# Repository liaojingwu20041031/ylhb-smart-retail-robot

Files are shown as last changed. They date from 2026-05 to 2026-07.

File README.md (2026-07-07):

<div align="center">

# 🤖 YLHB Smart Retail Robot

### ROS 2 + Jetson Orin Nano Super 驱动的多模态智慧零售机器人

**一台会听、会看、会推荐、会导航的比赛级智能零售机器人。**

面向智慧零售竞赛场景，完整打通 **ZLAC8015D 底盘控制 / SLAM 建图 / Nav2 导航 / ZED 2i 视觉 / YOLO 商品识别 / 大模型任务理解 / 连续语音交互 / 现场 UI 总控台**。

<p>
  
  
  
  
  
  
  
  
  
</p>

<p>
  <strong>比赛主线：</strong>
  语音/文字任务理解 -> 货架导航 -> 商品识别 -> 推荐与确认 -> 取货/结算 -> 返回起点
</p>

<p>
  <a href="#-快速开始">快速开始</a> ·
  <a href="#-常用启动命令">启动命令</a> ·
  <a href="#-比赛任务流程">比赛任务</a> ·
  <a href="#-机械与-cad-资料">机械 CAD</a> ·
  <a href="#-系统架构">系统架构</a> ·
  <a href="src/PROJECT_DOC_zh.md">详细文档</a>
</p>

```bash
./scripts/setup_zlac_can.sh can1 500000
./scripts/run_on_jetson.sh competition
```

</div>

---

## 🎯 项目定位

这个仓库是一个面向 Jetson 本机部署的 ROS 2 工作区源码仓库，不是单节点 demo。它把底盘、传感器、导航、视觉检测、大模型任务理解、连续语音和比赛 UI 组织成一套可现场运行的机器人系统。

默认底盘后端是 **ZLAC8015D V4 + SocketCAN/CANopen**；保留 STM32 串口后端作为回退方案。比赛现场推荐从 `./scripts/run_on_jetson.sh competition` 进入，由 UI 和 system supervisor 编排底层、视觉、导航和 AI 节点。

当前版本重点解决的是“能在 Jetson 本机独立跑完整比赛链路”：显示屏 UI 负责现场操作和状态展示，system supervisor 负责按顺序拉起 ROS 2 节点，AI 任务层负责把图片、文字和语音输入转换成机器人可执行事件，底盘/导航/视觉栈负责完成移动和商品识别。

## ✨ 项目亮点

| 方向 | 能力 |
|---|---|
| 🚗 机器人底盘 | ZLAC8015D SocketCAN 默认后端、STM32 串口回退、IMU 驱动、RPLidar 雷达、URDF 模型、EKF 融合 |
| 🗺️ 建图与导航 | SLAM Toolbox 建图、AMCL 定位、Nav2 自主导航、地图保存与加载 |
| 👁️ 视觉感知 | ZED 2i 图像订阅、YOLO26 商品检测、TensorRT 推理、检测结果发布 |
| 🧠 多模态 AI | DashScope/Qwen 图片理解、文字/语音任务解析、商品推荐、结算播报 |
| 🎙️ 连续语音 | eMeet Luna 麦克风输入、唤醒词连续语音会话、ASR 事件路由、TTS 播报 |
| 🖥️ 比赛 UI | A/B/C/D 任务入口、B-1 图片预览、识别结果、购物车、总价、系统总控台 |

> 本仓库不提交 `build/`、`install/`、`log/`、API Key 和模型二进制文件。克隆后需要在目标 Jetson 上本机构建。

## ✅ 当前交付范围

| 模块 | 状态 | 说明 |
|---|---|---|
| Jetson 本机部署 | ✅ 可用 | 依赖安装、构建、运行入口集中在 `scripts/` |
| ZLAC8015D 底盘 | ✅ 默认 | 默认使用 PEAK PCAN-USB 暴露的 SocketCAN `can1`，速率 500000 |
| STM32 底盘 | ✅ 回退 | `base_backend:=stm32` 可切换到旧串口链路 |
| SLAM / Nav2 | ✅ 可用 | 比赛默认地图为 `maps/my_map.yaml`，`src/my_map.yaml` 仅作兼容回退；UI 和移动端保存地图已统一 10 秒等待超时 |
| ZED + YOLO26 | ✅ 可用 | 默认加载 Jetson 本机 TensorRT engine |
| 多模态任务层 | ✅ 可用 | 支持任务书图片、文字指令、商品推荐和购物车状态 |
| 连续语音 / TTS | ✅ 可用 | 默认面向 eMeet Luna，唤醒后进入连续对话 |
| 比赛总控 UI | ✅ 可用 | 提供任务入口、节点控制、地图保存、识别和结算展示 |
| 机械 CAD 资料 | ✅ 已归档 | 小车底盘、万向轮、支架、顶板、Jetson 固定板和语音模块支架等结构件 |
| 演示素材 | ⏳ 补充中 | 后续补充高质量截图、GIF、实机视频和英文 README |

---

## 🧭 系统架构

```mermaid
flowchart TB
    subgraph Interaction[交互与比赛入口]
      User["用户 / 裁判<br/>语音 · 文字 · 任务书图片"]
      UI["比赛显示屏 UI<br/>A/B/C/D 任务入口 · 购物车 · 总控台"]
      Voice["eMeet Luna<br/>唤醒词 · 连续语音 · ASR"]
      TTS["TTS 播报<br/>推荐结果 · 结算状态 · 导航反馈"]
    end

    subgraph Intelligence[AI 任务编排层]
      TaskCore["ylhb_llm 任务核心<br/>意图解析 · 商品推荐 · 任务状态机"]
      Qwen["DashScope / Qwen<br/>视觉理解 · 文本推理 · ASR/TTS"]
      EventBus["/retail_ai/task_event/<br/>任务事件与 UI 状态同步"]
    end

    subgraph ROS[ROS 2 通信与运行时]
      Topics["核心话题<br/>/cmd_vel · /odom · /scan · /image · /detections"]
      Launch["run_on_jetson.sh<br/>bringup · zed · perception · navigation · llm"]
      Supervisor["System Supervisor<br/>比赛节点编排与健康状态"]
    end

    subgraph Robot[机器人执行栈]
      Base["底盘控制<br/>ZLAC8015D 默认 · STM32 回退 · 轮式里程计"]
      IMU["IMU<br/>姿态与角速度"]
      Lidar["RPLidar<br/>2D 激光扫描"]
      ZED["ZED 2i<br/>RGB · Depth · Camera Info"]
      EKF["robot_localization<br/>EKF 位姿融合"]
      SLAM["SLAM Toolbox<br/>建图与地图保存"]
      Nav2["Nav2 / AMCL<br/>定位 · 路径规划 · 避障"]
      Perception["YOLO26 + TensorRT<br/>商品检测 · 调试图像"]
    end

    User --> UI
    User --> Voice
    UI --> TaskCore
    Voice --> TaskCore
    TaskCore <--> Qwen
    TaskCore --> EventBus
    EventBus --> UI
    TaskCore --> TTS

    UI --> Supervisor
    Supervisor --> Launch
    Launch --> Topics
    EventBus --> Nav2

    Topics --> Base
    Base --> Topics
    IMU --> Topics
    Lidar --> Topics
    ZED --> Topics
    Topics --> EKF
    Topics --> SLAM
    Topics --> Nav2
    Topics --> Perception
    Perception --> TaskCore
    Nav2 --> Base
```

---

## 📦 目录结构

```text
.
├── scripts/
│   ├── install_jetson_dependencies.sh   # Jetson 依赖安装
│   ├── build_on_jetson.sh               # 本机构建入口
│   ├── setup_zlac_can.sh                # ZLAC8015D SocketCAN 配置
│   └── run_on_jetson.sh                 # 现场运行入口
├── CAD/
│   └── Retail-Cart-3D-Model/            # 机械同学提供的小车结构 CAD 与 STL 文件
├── maps/
│   ├── my_map.yaml                      # 比赛推荐导航地图
│   └── my_map.pgm
├── src/
│   ├── ylhb_base/                       # 底盘、IMU、URDF、EKF、SLAM、Nav2
│   ├── ylhb_perception/                 # ZED、YOLO/TensorRT、深度定位
│   ├── ylhb_llm/                        # 大模型任务层、语音、TTS、比赛 UI
│   ├── ylhb_interfaces/                 # 自定义 ROS 2 消息
│   ├── rplidar_ros-ros2/                # RPLidar ROS 2 驱动源码
│   ├── zed-ros2-wrapper/                # ZED ROS 2 wrapper 源码
│   ├── PROJECT_DOC_zh.md                # 详细中文开发与比赛调试文档
│   ├── my_map.yaml
│   └── my_map.pgm
├── MIGRATION_JETSON.md                  # Jetson 本机化迁移说明
└── SECURITY.md                          # 安全与密钥规范
```

---

## 🧩 硬件与软件环境

### 硬件组成

| 模块 | 设备 | 用途 |
|---|---|---|
| 主控 | Jetson Orin Nano Super | 运行 ROS 2、Nav2、感知节点、AI 任务层和显示屏 UI |
| 底盘控制 | ZLAC8015D V4 双轮毂伺服驱动器 | 默认后端；通过 SocketCAN/CANopen 接收 `/cmd_vel`，发布 `/odom`、`/zlac8015d/status`、`/zlac8015d/fault` |
| 底盘回退 | STM32 大脑底板 | 串口回退后端；用于旧底盘链路调试和备用运行 |
| 雷达 | RPLidar | 发布 `/scan`，用于 SLAM、AMCL 定位和 Nav2 避障 |
| 相机 | ZED 2i | 发布 RGB 图、深度图和相机内参，供 YOLO 和 3D 粗定位使用 |
| IMU | 底盘 IMU | 与轮式里程计进入 EKF，提高短时位姿稳定性 |
| 语音 | eMeet Luna | 麦克风输入、TTS 播放；推荐录音设备 `plughw:CARD=Luna,DEV=0` |
| 显示 | Jetson 本机 HDMI / 触摸屏 | 比赛 UI、任务 D 驾驶舱和现场总控台 |
| 机械结构 | 自研零售小车底盘与支架 | CAD 文件已归档到 `CAD/Retail-Cart-3D-Model/`，包含底盘、万向轮、顶板、Jetson 固定板和语音模块支架 |

### 软件栈

| 类型 | 组件 |
|---|---|
| 系统 | Ubuntu 22.04 / ROS 2 Humble |
| 导航 | SLAM Toolbox、Nav2、AMCL、robot_localization |
| 视觉 | ZED ROS 2 wrapper、OpenCV、CUDA、TensorRT、YOLO26 |
| AI | DashScope OpenAI 兼容接口、Qwen 视觉/文本/ASR/TTS 模型 |
| UI | PyQt 比赛显示屏总控台 |

---

## 🧱 机械与 CAD 资料

机械结构文件位于 [CAD/Retail-Cart-3D-Model](CAD/Retail-Cart-3D-Model)，用于复现或修改智慧零售小车的物理结构。

| 路径 | 内容 |
|---|---|
| `CAD/Retail-Cart-3D-Model/sldasm/` | SolidWorks 装配文件，包括小车底盘和万向轮装配 |
| `CAD/Retail-Cart-3D-Model/stp/` | SolidWorks 零件文件，包括上底盘、顶板、支撑杆、伸缩柱、电机轮、电池、驱动器、Jetson 固定板、语音模块支架等 |
| `CAD/Retail-Cart-3D-Model/stl/` | 可用于 3D 打印的结构件 STL 文件 |
| `CAD/Retail-Cart-3D-Model/readme.txt` | 3D 打印数量备注 |

当前 3D 打印备注：`支架垫片` 4 个，`固定盖` 2 个，`底盘连接处支架` 2 个。机械件用于承载 Jetson、语音模块、驱动器、电池、底盘连接件和上层展示/交互结构。

---

## 🚀 快速开始

默认工作区路径是 `~/ros2_ws`。如果克隆到其他目录，请先设置：

```bash
export WS_DIR=/path/to/ros2_ws
```

在 Jetson 上克隆仓库：

```bash
cd ~
git clone https://github.com/liaojingwu20041031/ylhb-smart-retail-robot.git ros2_ws
cd ~/ros2_ws
```

安装依赖并构建：

```bash
./scripts/install_jetson_dependencies.sh
./scripts/build_on_jetson.sh
```

`scripts/run_on_jetson.sh` 会自动加载 `/opt/ros/$ROS_DISTRO/setup.bash` 和 `install/setup.bash`，日常启动不需要手动 `source`。

首次连接 ZLAC8015D 前，先配置 CAN 口：

```bash
./scripts/setup_zlac_can.sh can1 500000
ip -br link show can1
```

自研包验证命令：

```bash
PYTHONNOUSERSITE=1 colcon test \
  --packages-select ylhb_base ylhb_perception ylhb_llm ylhb_interfaces \
  --event-handlers console_direct+
```

> 仓库包含 ZED/RPLidar 第三方源码。第三方包用于部署构建，默认不把 vendor lint 作为项目质量门槛；完整 `colcon test` 可能因第三方包格式规则或离线 schema 校验失败。

---

## 🕹️ 常用启动命令

`scripts/run_on_jetson.sh` 是 Jetson 现场推荐入口，支持以下模式：

```text
bringup       启动底盘、IMU、雷达、URDF、EKF
mapping       启动 SLAM Toolbox 建图
navigation    启动 Nav2，默认地图为 ~/ros2_ws/maps/my_map.yaml，缺失时回退到 ~/ros2_ws/src/my_map.yaml
zed           启动 ZED 2i wrapper
perception    启动 TensorRT YOLO 感知节点
llm           启动 AI 任务层、语音节点和可选 UI
competition   启动比赛显示屏 UI、system supervisor 和内嵌 AI 任务层
teleop        启动键盘遥控
```

### 比赛现场一键入口

```bash
./scripts/run_on_jetson.sh competition
```

`competition` 默认启动显示屏 UI、系统 supervisor、AI 任务层、VLM shelf/checkout 节点、连续语音会话和 TTS 播报。进入 UI 的“系统控制”页后，点击“一键启动比赛节点”，supervisor 会按保分模式启动底层栈：

```text
bringup -> zed -> navigation -> llm
```

顺序启动比赛栈。其中 AI 任务层已随 `competition` 内嵌运行，状态会显示为 `embedded`，不会重复启动。

### 当前比赛保分模式

当前 `competition` 入口等价于 score-safe 栈：

- 默认启用 `retail_competition_executor_node`、`vlm_shelf_recognition_node` 和 `vlm_checkout_recognition_node`。
- 机械臂接口预留，默认 `competition_safe_mode:=true enable_real_arm:=false skip_arm_pick_place:=true`，只发布抓取/放置 skipped 成功状态。
- B-1/B-2/C 的商品识别由 ZED 当前图像进入 VLM 完成；YOLO/TensorRT 是增强模式，不是当前保分模式硬依赖。
- 比赛前必须按实际地图标定 S/A/B 点位，更新 `maps/routes/retail_competition_route.json` 或通过 `route_file:=...` 指向实测路线文件。仓库中的占位路线只用于格式示例，不能直接上场。

调试图片兜底：

```bash
./scripts/run_on_jetson.sh competition \
  shelf_image_path:=/home/nvidia/ros2_ws/src/ylhb_llm/test_images/shelf.jpg \
  checkout_image_path:=/home/nvidia/ros2_ws/src/ylhb_llm/test_images/checkout.jpg
```

启用 YOLO/TensorRT 增强感知时，再显式启动：

```bash
./scripts/run_on_jetson.sh competition start_yolo_perception:=true
```

默认参数：

```text
enable_voice:=true
enable_voice_session:=true
enable_capture_voice:=false
enable_tts:=true
audio_input_device:=plughw:CARD=Luna,DEV=0
audio_output_device:=default
tts_voice:=Serena
```

现场临时静音：

```bash
./scripts/run_on_jetson.sh competition enable_tts:=false
```

远程 X11 调试窗口模式：

```bash
./scripts/run_on_jetson.sh competition force_local_display:=false fullscreen:=false
```

### 单模块调试

```bash
# 底盘、IMU、雷达、URDF 和 EKF
./scripts/install_ch341_safe.sh --precheck
./scripts/install_ch341_safe.sh --test-load
sudo ./src/bind_usb.sh
./scripts/setup_zlac_can.sh can1 500000
./scripts/run_on_jetson.sh bringup

# STM32 串口回退底盘
./scripts/run_on_jetson.sh bringup base_backend:=stm32

# ZED 2i
./scripts/run_on_jetson.sh zed

# 大模型任务层，无语音无 TTS
export DASHSCOPE_API_KEY=你的DashScopeKey
./scripts/run_on_jetson.sh llm enable_voice:=false enable_tts:=false
```

启动视觉检测：

```bash
./scripts/run_on_jetson.sh perception \
  model_path:=/home/nvidia/ros2_ws/src/ylhb_perception/models/yolo26.engine \
  backend:=tensorrt \
  imgsz:=960 \
  confidence_threshold:=0.35 \
  max_det:=20 \
  half:=true \
  publish_debug_image:=false \
  log_interval_sec:=2.0 \
  device:=cuda:0
```

---

## 🎙️ 语音交互

项目推荐使用唤醒式连续语音模式。UI 中点击“开启语音模式”后，机器人本地监听人声；听到“小零小零”“小玲小玲”等唤醒词后进入会话。

接入 eMeet Luna 后，先确认系统能看到声卡：

```bash
lsusb | grep -i emeet
arecord -l
aplay -l
```

启动连续语音和 TTS：

```bash
export DASHSCOPE_API_KEY=你的DashScopeKey
./scripts/run_on_jetson.sh llm \
  enable_voice:=true \
  enable_voice_session:=true \
  enable_tts:=true \
  audio_input_device:=plughw:CARD=Luna,DEV=0 \
  audio_output_device:=plughw:CARD=Luna,DEV=0 \
  tts_voice:=Serena
```

连续语音服务和调试话题：

```bash
ros2 service call /retail_ai/start_voice_session std_srvs/srv/Trigger "{}"
ros2 service call /retail_ai/stop_voice_session std_srvs/srv/Trigger "{}"
ros2 topic echo /retail_ai/voice_session_status
ros2 topic echo /retail_ai/voice_command_event
```

---

## 🏁 比赛任务流程

项目按比赛任务 A/B/C/D 组织运行：

| 任务 | 流程 |
|---|---|
| A | 语音、文字或键盘命令转换为 `/cmd_vel`，完成前进、后退、转向、停止等基础动作 |
| B-1 | 导入任务书图片，大模型理解任务，导航到货架 A，识别真实商品，推荐商品，抓取后前往结算区 B |
| B-2 | 接收购物需求或商品指令，大模型像销售员一样给出主推和备选商品；用户确认后才发布取货事件 |
| C | 识别结算区商品，播报商品清单，根据 `products.yaml` 计算总价并返回起点 S |
| D | 通过现场显示屏 UI 展示任务状态、识别结果、播报文本、购物车和结算信息 |

任务书图片分析服务：

```bash
# 图片放在 /home/nvidia/ros2_ws/src/ylhb_llm/test_images
# 目录内只保留一张 .jpg/.jpeg/.png
ros2 service call /retail_ai/start_b1_task std_srvs/srv/Trigger "{}"
```

主要 AI/语音/UI 话题和服务：

```text
/retail_ai/task_event              # TaskEvent，inspect_shelf_for_recommendation / pick_item / checkout / return_start
/retail_ai/task_status             # TaskStatus，执行层回传 started/succeeded/failed/rejected
/retail_ai/sales_dialogue_status   # B-2 销售对话状态 JSON
/retail_ai/voice_command_event     # 连续语音 ASR 事件 JSON
/retail_ai/voice_session_status    # 连续语音会话状态 JSON
/retail_ai/capture_voice           # 单次录音 ASR service，competition 默认关闭
/retail_ai/start_voice_session     # 开启连续语音 service
/retail_ai/stop_voice_session      # 关闭连续语音 service
```

文字入口：

```bash
ros2 topic pub --once /retail_ai/text_command std_msgs/msg/String "{data: '来瓶可乐'}"
ros2 topic pub --once /retail_ai/text_command std_msgs/msg/String "{data: '我口渴了'}"
ros2 topic pub --once /retail_ai/text_command std_msgs/msg/String "{data: '确认'}"
ros2 topic echo /retail_ai/task_event
ros2 topic echo /retail_ai/sales_dialogue_status
ros2 topic echo /retail_ai/say_text
```

---

## 🧰 现场运行自检

比赛前建议按从硬件到任务层的顺序检查，能更快定位是设备、驱动、模型还是 AI Key 问题。

### 设备检查

```bash
# CAN 与 ZLAC8015D
ip -details link show can1

# USB 设备与音频设备
lsusb
arecord -l
aplay -l

# ROS 2 包是否已构建并可见
source install/setup.bash
ros2 pkg list | grep -E 'ylhb_base|ylhb_perception|ylhb_llm|ylhb_interfaces'
```

### 节点与话题检查

```bash
# 底盘与传感器
lsmod | grep -E 'ch341|ch34x'
lsusb
dmesg | grep -i ch34
ls -l /dev/robot_imu /dev/ttyCH341USB* /dev/ttyUSB*
ros2 topic echo /odom
ros2 topic echo /scan
ros2 topic echo /imu/data --once

# ZED 与视觉检测
ros2 topic hz /zed/zed_node/rgb/color/rect/image
ros2 topic echo /detections

# AI 任务层与语音
ros2 topic echo /retail_ai/task_event
ros2 topic echo /retail_ai/task_status
ros2 topic echo /retail_ai/voice_session_status
```

### 常见现场处理

| 现象 | 优先检查 |
|---|---|
| 底盘不响应 `/cmd_vel` | `can1` 是否 `UP`、ZLAC 是否上电、急停/使能状态、`/zlac8015d/fault` |
| 雷达无 `/scan` | `/dev/robot_lidar` 绑定、串口权限、RPLidar 电源和转速 |
| UI 无法显示 | Jetson 本机 `DISPLAY=:0`、HDMI/触摸屏连接、远程调试时加 `force_local_display:=false fullscreen:=false` |
| 视觉节点退出 | `yolo26.engine` 是否存在、engine 是否在当前 Jetson 编译、ZED 图像话题是否有帧 |
| 大模型无响应 | `DASHSCOPE_API_KEY` 是否已导出、网络是否可用、模型参数是否被覆盖 |
| 语音无输入/输出 | eMeet Luna 声卡编号、`audio_input_device` / `audio_output_device`、系统音量和默认声卡 |

---

## 🗺️ 建图与导航

启动建图：

```bash
./scripts/run_on_jetson.sh mapping
```

建图时推荐使用低速键盘遥控：

```bash
source /opt/ros/humble/setup.bash

ros2 run teleop_twist_keyboard teleop_twist_keyboard \
  --ros-args \
  -p speed:=0.08 \
  -p turn:=0.25
```

其中 `speed` 是线速度，单位 `m/s`；`turn` 是角速度，单位 `rad/s`。

启动导航：

```bash
./scripts/run_on_jetson.sh navigation
```

比赛默认把机器人放在建图起点附近，AMCL 启动时会先使用地图原点 `(0, 0, 0)` 发布定位。若现场启动位置偏离建图起点，请先在 RViz/Foxglove 发布 `/initialpose` 覆盖默认位姿，再发送导航目标。

默认导航地图：

```text
~/ros2_ws/maps/my_map.yaml
~/ros2_ws/maps/my_map.pgm
```

推荐比赛导航地图来自实机 SLAM 保存，地图图像为 `195 x 333`，分辨率 `0.05 m/pix`。`~/ros2_ws/src/my_map.yaml` 仅作为兼容回退地图。

巡检路线标注工具的小车俯视模型参考 `/home/nvidia/ros2_DL/src/ylhb_base/config/nav2_params.yaml` 中的 Nav2 `footprint` 和 `footprint_padding`，导出前按整车占地检查地图空闲区。

UI 的“保存地图”默认写入：

```text
~/ros2_ws/src/maps/<map_name>.yaml/.pgm
```

UI 和移动端调试接口保存地图时都会调用：

```bash
ros2 run nav2_map_server map_saver_cli -f <target> --ros-args -p save_map_timeout:=10.0
```

这个等待时间用于覆盖 SLAM Toolbox 发布 `/map` 的实际节奏，避免 Nav2 默认 2 秒订阅等待偶发超时。

导航默认优先读取 `~/ros2_ws/maps/my_map.yaml`。要使用新保存的地图，需要复制成推荐默认地图、保持为回退地图，或启动导航时覆盖 `map:=...`。

---

## 🧠 模型文件说明

模型二进制文件不提交到 GitHub。需要在 Jetson 上准备：

```text
/home/nvidia/ros2_ws/src/ylhb_perception/models/yolo26.onnx
/home/nvidia/ros2_ws/src/ylhb_perception/models/yolo26.engine
```

PC 端导出 ONNX 后，将 `yolo26.onnx` 放入 `src/ylhb_perception/models/`，再在 Jetson 上编译 TensorRT engine：

```bash
ros2 run ylhb_perception export_yolo_trt.py \
  --onnx /home/nvidia/ros2_ws/src/ylhb_perception/models/yolo26.onnx \
  --output /home/nvidia/ros2_ws/src/ylhb_perception/models/yolo26.engine \
  --workspace 2048
```

DashScope API Key 不写入代码。运行图片理解、云端 ASR 或云端 TTS 前，在终端设置：

```bash
export DASHSCOPE_API_KEY=你的DashScopeKey
```

推荐把 API Key 放在本机 shell 配置或现场启动脚本外部注入，不要写进 launch 文件、Python 源码、README 示例之外的配置文件或 Git 跟踪文件。

## 🧪 适合谁参考？

- 正在做 ROS 2 智能车、移动机器人或比赛项目的同学
- 想把 Jetson、ZED、Nav2、YOLO、LLM 接成完整系统的开发者
- 需要智慧零售、服务机器人、多模态交互参考架构的团队
- 想学习“比赛工程如何从 demo 变成交付系统”的机器人爱好者

---

## 📌 Roadmap

- [x] Jetson 本机化部署
- [x] Nav2 / SLAM / EKF 基础运动栈
- [x] ZED 2i + YOLO26 + TensorRT 感知链路
- [x] DashScope/Qwen 多模态任务理解
- [x] 唤醒式连续语音会话
- [x] 比赛显示屏 UI 与 system supervisor
- [ ] 补充高质量演示 GIF、系统截图和视频链接
- [ ] 补充英文 README
- [ ] 增加 CI 检查自研 ROS 2 包
- [ ] 整理可复用的机器人任务编排框架

---

## 🔒 安全与规范

- 不提交 `DASHSCOPE_API_KEY`、`.env`、SSH key、证书或其他本机密钥。
- 不提交 `.onnx`、`.engine`、`.pt` 等模型二进制文件。
- 串口权限优先使用 udev 规则或用户组，不建议长期使用 `chmod 777`。
- 安全和部署注意事项见 [SECURITY.md](SECURITY.md)。

---

## 📚 详细文档

- [src/PROJECT_DOC_zh.md](src/PROJECT_DOC_zh.md)：比赛调试顺序、节点关系、话题流向、启动命令和常见问题。
- [MIGRATION_JETSON.md](MIGRATION_JETSON.md)：从旧 PC 推流识别流程迁移到 Jetson 本机开发、本机构建、本机运行。

---

## ⭐ 支持项目

如果这个项目对你做 ROS 2、Jetson、机器人比赛或多模态 AI Agent 有帮助，欢迎点一个 **Star**。  
后续会继续补充演示视频、部署文档和比赛实战记录。

<div align="center">

**YLHB Smart Retail Robot — 让机器人从“能跑”走向“能听懂、看懂、会执行”。**

</div>

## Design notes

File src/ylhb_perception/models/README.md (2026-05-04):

# YOLO26 模型目录

最终部署流程：

```text
PC 训练 YOLO -> PC 导出 yolo26.onnx -> 复制到 Jetson -> Jetson 编译 yolo26.engine -> Jetson 运行 engine
```

推荐文件：

```text
yolo26.pt       # 原始训练权重，留给 PC 端训练/导出
yolo26.onnx     # PC 端导出的跨平台中间模型
yolo26.engine   # Jetson 本机编译出的 TensorRT FP16 推理引擎，实时检测默认使用
```

Jetson 端一次性编译 TensorRT engine：

```bash
cd ~/ros2_ws
source install/setup.bash
ros2 run ylhb_perception export_yolo_trt.py \
  --onnx /home/nvidia/ros2_ws/src/ylhb_perception/models/yolo26.onnx \
  --output /home/nvidia/ros2_ws/src/ylhb_perception/models/yolo26.engine \
  --workspace 2048
```

Jetson 实时推理：

```bash
ros2 launch ylhb_perception perception.launch.py \
  model_path:=/home/nvidia/ros2_ws/src/ylhb_perception/models/yolo26.engine \
  backend:=tensorrt \
  imgsz:=960 \
  half:=true \
  device:=cuda:0
```

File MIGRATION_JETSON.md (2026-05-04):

# Jetson 本机化迁移备忘

这个文件只记录迁移背景和工程边界。日常使用请看：

```text
~/ros2_ws/src/PROJECT_DOC_zh.md
```

---

## 1. 迁移目标

项目现在以 Jetson Orin Nano Super 本机开发、本机构建、本机运行为准。

默认工作区路径是 `~/ros2_ws`。如需部署到其他目录，先设置：

```bash
export WS_DIR=/path/to/ros2_ws
```

旧流程已经废弃：

```text
PC 端开发
PC 端做视觉识别
开发板向 PC 推流
PC 再把识别结果回传开发板
```

新流程：

```text
Jetson 本机开发
Jetson 本机构建
Jetson 本机启动 ROS 2
Jetson 本机运行 ZED 2i + YOLO26
```

---

## 2. 当前职责边界

```text
ylhb_base
  底盘、IMU、URDF、EKF、雷达、建图、导航

ylhb_perception
  ZED 图像订阅、YOLO26 检测、调试图、ZED 深度定位

zed-ros2-wrapper
  第三方 ZED 驱动，只负责相机输出

rplidar_ros-ros2
  第三方雷达驱动，只负责 /scan 输出
```

---

## 3. 关键变化

新增：

```text
scripts/install_jetson_dependencies.sh
scripts/build_on_jetson.sh
scripts/run_on_jetson.sh
src/ylhb_perception/
```

调整：

```text
src/ylhb_base/scripts/vision_node.py
```

现在它只是兼容桥，不再负责 PC 推流和 PC 回传。

导航默认地图：

```text
~/ros2_ws/src/my_map.yaml
```

---

## 4. 后续开发原则

```text
底盘和导航逻辑继续放 ylhb_base
视觉和 AI 逻辑放 ylhb_perception
不要改第三方 vendor 包来塞业务逻辑
不要再恢复 PC 推流识别流程
```

---

## 5. 最重要的推理入口

PC 端导出 ONNX，Jetson 端执行一次 ONNX 到 TensorRT engine 的本机编译。

PC 端导出 ONNX 后，把文件放到：

```text
/home/nvidia/ros2_ws/src/ylhb_perception/models/yolo26.onnx
```

Jetson 端一次性编译 TensorRT engine：

```bash
ros2 run ylhb_perception export_yolo_trt.py \
  --onnx /home/nvidia/ros2_ws/src/ylhb_perception/models/yolo26.onnx \
  --output /home/nvidia/ros2_ws/src/ylhb_perception/models/yolo26.engine \
  --workspace 2048
```

ZED + YOLO TensorRT 实时检测：

```bash
ros2 launch zed_wrapper zed_camera.launch.py camera_model:=zed2i
ros2 launch ylhb_perception perception.launch.py \
  model_path:=/home/nvidia/ros2_ws/src/ylhb_perception/models/yolo26.engine \
  backend:=tensorrt \
  imgsz:=960 \
  confidence_threshold:=0.35 \
  max_det:=20 \
  half:=true \
  publish_debug_image:=false \
  log_interval_sec:=2.0 \
  device:=cuda:0
```

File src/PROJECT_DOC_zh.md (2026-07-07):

# ROS2 智能车比赛项目开发文档

平台：Jetson Orin Nano Super  
工作区：`~/ros2_ws`  
核心任务：**建图、导航、AI 识别**

本文档按比赛调试顺序编写，重点说明每个模块的技术原理、节点关系、话题流向、启动命令、验收标准和常见问题。

---

## 0. 比赛主流程

比赛准备和调试时，不要从单个脚本开始理解项目，先看主流程：

```text
1. 底层启动
   ZLAC8015D SocketCAN 底盘后端（默认）或 STM32 串口回退 + IMU + 雷达 + URDF + EKF

2. 建图
   RPLidar + 里程计 + TF -> SLAM Toolbox -> 保存 my_map.yaml / my_map.pgm

3. 导航
   已知地图 + AMCL 定位 + Nav2 规划控制 -> /cmd_vel -> 底盘运动

4. AI 识别
   保分模式：ZED 2i 图像 -> VLM shelf/checkout 识别
   增强模式：ZED 2i 图像 -> YOLO26 -> 检测结果 / 本地窗口调试 / 深度定位

5. 比赛整合
   大模型任务层 -> 图片理解 / 语音文字指令解析 / 商品推荐 / 结算流程 -> 导航抓取任务事件
```

当前比赛任务流程按 A/B/C 三类处理：

```text
任务 A-1：
键盘或语音/文字发布前进、后退、左转、右转、停止 -> /cmd_vel -> 底盘动作。
规则没有要求每个基本动作都 AI 播报，所以项目不把“好的，开始前进”写成固定播报。

任务 A-2：
语音交互内容以现场任务书为准，不提前写死台词。语音经 ASR 进入 /retail_ai/text_command。

任务 B-1：
导入任务书图片 -> 大模型理解图片并播报理解内容 -> 发布“去货架 A 识别”事件
-> 到 A 区后识别货架真实商品 -> 从真实货架商品中推荐 1 个最佳商品并播报
-> 抓取推荐商品 -> 导航到结算区 B -> 放置商品。

任务 B-2：
接收文字或语音购物指令 -> 识别目标商品 -> 播报相应信息
-> 导航到货架 A -> 识别货架真实商品 -> 抓取目标商品
-> 导航到结算区 B -> 放置商品 -> 返回起点 S。

任务 C：
接收结算指令 -> 导航到结算区 B -> 识别结算区内所有商品
-> 播报商品清单 -> 返回起点 S -> 按 products.yaml 价格表计算并播报总价。
```

当前比赛保分模式手动启动：

```bash
cd ~/ros2_ws
./scripts/run_on_jetson.sh competition fullscreen:=true
```

该入口默认启用 VLM 货架/结算识别和 safe executor，机械臂真实接口默认跳过。比赛前必须按实际地图标定 S/A/B 点位，更新 `maps/routes/retail_competition_route.json` 或传入 `route_file:=实际路线文件`。仓库里的 A=(1,0)、B=(2,0) 只表示格式占位，不能作为现场路线。

推荐启动顺序：

> **🚗 核心指令：启动底层系统 (Bringup)**

```bash
# 终端 1：启动底盘、IMU、雷达、URDF、EKF
# 进入工作目录并加载环境变量
cd ~/ros2_ws
source /opt/ros/humble/setup.bash
source install/setup.bash
# 一键启动底盘、IMU、雷达、URDF、EKF。IMU 默认必启，缺失会直接报错退出。
ros2 launch ylhb_base bringup.launch.py

# 无 USB-CAN 线或需要回退旧底盘板时：
ros2 launch ylhb_base bringup.launch.py base_backend:=stm32
```

### 底层串口约定与验收

Jetson Orin Nano Super 当前硬件连接约定：

```text
10c4:ea60 Silicon Labs CP210x  -> RPLidar A2M8
1a86:7523 QinHeng CH340        -> IMU 的 USB 转 TTL 模块
0c72:000c PEAK PCAN-USB        -> ZLAC8015D CANopen 底盘
```

比赛机上不要手动 `insmod pcan.ko`、手动运行 `setup_zlac_can.sh`，也不要在每次启动时临时传 `lidar_port:=...`。统一执行一次：

```bash
sudo ./src/bind_usb.sh
```

该脚本会安装并启用 `robot-hardware-guard.service`，循环恢复以下状态：

```text
/dev/robot_lidar -> ttyUSBx       # CP2102 LiDAR，驱动 cp210x
/dev/robot_imu   -> ttyCH341USBx  # CH340 IMU，驱动 usb_ch341
can1             -> PEAK PCAN-USB # 500000 bit/s, berr-reporting on, restart-ms 100, UP
```

安装验收：

```bash
systemctl status robot-hardware-guard.service --no-pager
tail -n 120 /var/log/robot-hardware-guard.log
lsusb -t
ls -l /dev/robot_lidar /dev/robot_imu /dev/ttyUSB* /dev/ttyCH341USB*
ip -details link show can1
```

期望结果：

```text
10c4:ea60 -> Driver=cp210x
1a86:7523 -> Driver=usb_ch341
0c72:000c -> Driver=pcan
/dev/robot_lidar -> ttyUSB0 或其他 ttyUSBx
/dev/robot_imu -> ttyCH341USB0 或其他 ttyCH341USBx
can1 state UP, bitrate 500000, ERROR-ACTIVE
```

`bringup.launch.py` 中 LiDAR 默认使用 `/dev/robot_lidar`。如果 alias 短暂不存在，launch 会按 USB ID `10c4:ea60` 自动查找 CP2102 的 `/dev/ttyUSB*` 作为回退；硬件修复仍然交给 `robot-hardware-guard.service`，ROS launch 只负责检测和报错。

RPLidar A2M8 固定按 `115200` 启动，launch 中将 `lidar_baudrate` 强制作为 int 传给 `rplidar_node`，避免参数类型错误导致节点回退到源码默认的 `1000000` 波特率。正常启动时必须看到类似日志：

```text
RPLidar serial config: port=... baudrate=115200 frame_id=laser_link
RPLidar S/N: ...
RPLidar health status : OK.
current scan mode: Sensitivity ... scan frequency:10.0 Hz
```

雷达验收：

```bash
ros2 topic echo /scan --once
```

如果雷达再次出现 `SL_RESULT_OPERATION_TIMEOUT`，先看日志中的 `RPLidar serial config`，确认端口是 `/dev/robot_lidar` 或 CP2102 回退端口且 `baudrate=115200`；不要再把 CH340 当成雷达端口排查。

IMU 当前注意事项：CH340 能出现在 `lsusb` 里只表示 USB 枚举成功，不等于 Linux 已经创建 tty 串口。当前 Jetson 内核配置为 `# CONFIG_USB_SERIAL_CH341 is not set` 时，`1a86:7523` 不会生成 `/dev/ttyUSB*`。本仓库使用 WCH `usb_ch341` 驱动，正常设备名是 `/dev/ttyCH341USB*`，稳定别名是 `/dev/robot_imu`。标准修复顺序：

```bash
./scripts/install_ch341_safe.sh --precheck
./scripts/install_ch341_safe.sh --test-load
sudo ./src/bind_usb.sh
ls -l /dev/robot_imu /dev/ttyCH341USB* /dev/ttyUSB*
ros2 launch ylhb_base bringup.launch.py
```

当前 IMU 实测为 WIT 协议 `9600` 波特率。`imu_driver` 默认 `baud_rate:=9600`，并保留自动探测常见波特率能力；默认不在每次启动时改写 IMU 模块配置，避免现场设备参数被反复写入。

IMU 验收命令：

```bash
lsmod | grep -E 'ch341|ch34x'
lsusb
dmesg | grep -i ch34
ls -l /dev/robot_imu /dev/ttyCH341USB* /dev/ttyUSB*
ros2 topic echo /imu/data --once
```

> **📷 核心指令：启动 ZED 2i 相机节点**

```bash
# 终端 2：启动 ZED 2i 相机
cd ~/ros2_ws
source install/setup.bash
# 参数详解：
#   camera_model:=zed2i: 显式指定相机型号为 zed2i，底层驱动会自动加载出厂标定的内参与最佳分辨率配置
ros2 launch zed_wrapper zed_camera.launch.py camera_model:=zed2i
```

> **🧠 增强模式：启动 YOLO26 实时感知分析**

```bash
# 终端 3：启动 YOLO26 实时识别
cd ~/ros2_ws
source install/setup.bash
# 运行 AI 视觉流处理。调试看效果时打开本地窗口；比赛时关闭窗口和 ROS2 调试图。
# 参数详析：
#   model_path: Jetson 本机编译出的 TensorRT FP16 engine 绝对路径
#   backend: 日志标识和安全检查用，比赛部署固定使用 tensorrt
#   confidence_threshold: 0.35，偏重识别成功率，后续用连续帧稳定确认过滤误检
#   imgsz: 网络推理重采样尺寸，设定为 960，兼顾远距离小目标识别与算力
#   max_det: 最多保留 20 个检测框，降低 NMS 后处理开销
#   half: 保留 launch 参数兼容；实际精度由 yolo26.engine 编译方式决定
#   publish_debug_image: 默认 false，不走 ROS2 图像调试链路，避免 DDS/Foxglove/rqt 兼容和延迟问题
#   show_debug_window: 调试时设为 true，直接弹出本地 OpenCV 窗口看检测框
#   debug_window_max_hz: 本地调试窗口刷新上限，推荐 10~15
#   log_interval_sec: 每 2 秒输出 FPS、推理耗时和识别摘要
#   device: 保留 launch 参数兼容；C++ TensorRT 节点直接使用 Jetson CUDA Runtime

# 调试模式：直接弹出本地 OpenCV 窗口看检测效果
ros2 launch ylhb_perception perception.launch.py \
  model_path:=/home/nvidia/ros2_ws/src/ylhb_perception/models/yolo26.engine \
  backend:=tensorrt \
  confidence_threshold:=0.35 \
  imgsz:=960 \
  max_det:=20 \
  half:=true \
  publish_debug_image:=false \
  show_debug_window:=true \
  debug_window_max_hz:=15.0 \
  log_interval_sec:=2.0 \
  device:=cuda:0

# 增强模式：关闭所有可视化输出，只发布检测 JSON 和 3D 定位结果
ros2 launch ylhb_perception perception.launch.py \
  model_path:=/home/nvidia/ros2_ws/src/ylhb_perception/models/yolo26.engine \
  backend:=tensorrt \
  confidence_threshold:=0.35 \
  imgsz:=960 \
  max_det:=20 \
  half:=true \
  publish_debug_image:=false \
  show_debug_window:=false \
  debug_window_max_hz:=15.0 \
  log_interval_sec:=2.0 \
  device:=cuda:0
```

```bash
# 终端 4：建图或导航，二选一
# 建图
ros2 launch ylhb_base mapping.launch.py

# 已有地图时导航
ros2 launch ylhb_base navigation.launch.py
```

> **🤖 核心指令：启动大模型任务层**

```bash
# 终端 5：启动任务书图片理解、文字/语音指令解析、商品推荐、结算和播报队列
cd ~/ros2_ws
source /opt/ros/humble/setup.bash
source install/setup.bash

# DashScope API Key 不写进代码，比赛前在终端环境变量里设置
export DASHSCOPE_API_KEY=你的DashScope_API_Key

# 默认语音输入和 TTS 播放关闭，先用文字输入和 say_text 话题调试最稳
ros2 launch ylhb_llm llm.launch.py enable_voice:=false enable_tts:=false
```

任务书图片导入使用 service，不走连续图像 topic：

```bash
ros2 service call /retail_ai/start_b1_task std_srvs/srv/Trigger "{}"
```

B-1 service 不传图片路径；`retail_task_node` 会从
`/home/nvidia/ros2_ws/src/ylhb_llm/test_images` 中读取唯一一张 `.jpg/.jpeg/.png`
任务书图片。

文字指令兜底入口：

```bash
ros2 topic pub --once /retail_ai/text_command std_msgs/msg/String "{data: '来瓶可乐'}"
```

## 显示屏 UI 启动方法

显示屏 UI 是比赛现场总控台，也是任务 D“智慧零售驾驶舱”的展示入口。它负责任务选择、任务启动、建图/导航/感知/AI 任务层控制、识别结果显示、语音播报显示、购物车和总价显示。UI 只做控制入口和状态展示，不参与推荐、结算、抓取的核心决策；UI 进程退出不应影响已经启动的核心 ROS 节点继续运行。

### 单独启动 UI

```bash
cd ~/ros2_ws
ros2 run ylhb_llm retail_display_ui_node
```

单独启动 UI 前需要 ROS 环境已加载；日常比赛不推荐这种方式。若当前终端启用了 `set -u`，手动 `source /opt/ros/humble/setup.bash` 可能报 `AMENT_TRACE_SETUP_FILES: unbound variable`，此时先执行 `set +u` 再 source，或直接使用下面的 `run_on_jetson.sh` 包装脚本。

### 通过 launch 启动 UI

```bash
cd ~/ros2_ws
ros2 launch ylhb_llm llm.launch.py enable_display_ui:=true
```

通过 `ros2 launch` 手动启动同样要求 ROS 环境已加载。若只是比赛现场使用，优先使用 `./scripts/run_on_jetson.sh competition`。

### 比赛现场推荐启动

```bash
cd ~/ros2_ws
./scripts/run_on_jetson.sh competition
```

`run_on_jetson.sh` 会自动加载 `/opt/ros/$ROS_DISTRO/setup.bash` 和 `~/ros2_ws/install/setup.bash`，并且在加载时临时关闭 `set -u`，避免 ROS 官方 setup 脚本读取未定义变量时报错。

`competition` 默认启用连续语音会话和 TTS 播报；按键式单次录音 service 默认关闭。实际 launch 参数为 `enable_voice:=true`、`enable_voice_session:=true`、`enable_capture_voice:=false`、`enable_tts:=true`、`audio_input_device:=plughw:CARD=Luna,DEV=0`、`audio_output_device:=default`。启动后进入 UI 的“系统控制”页，点击“一键启动比赛节点”，由总控台启动底盘/雷达、ZED、感知和导航；不需要再手动打开其它终端。若现场需要临时静音：

```bash
./scripts/run_on_jetson.sh competition enable_tts:=false
```

`run_on_jetson.sh` 支持的模式：

```text
bringup       启动底盘、IMU、雷达、URDF、EKF
mapping       启动 slam_toolbox 建图
navigation    启动 Nav2，默认优先读取 ~/ros2_ws/maps/my_map.yaml，缺失时回退到 ~/ros2_ws/src/my_map.yaml
zed           启动 ZED 2i wrapper
perception    启动 TensorRT YOLO 感知节点
llm           启动 AI 任务层、语音和 UI 相关节点
competition   启动比赛 UI、supervisor 和内嵌 AI 任务层
teleop        启动键盘遥控
```

比赛现场接 Jetson 物理显示屏时使用本机显示：

```bash
export DISPLAY=:0
```

`DISPLAY=localhost:10.0` 是 SSH X11 转发，会把窗口转发到发起 SSH 的电脑；比赛现场物理屏幕必须使用 `DISPLAY=:0`。`competition` 脚本会自动把 SSH 转发 DISPLAY 改成 `:0`。如需远程 X11 调试，可使用：

```bash
./scripts/run_on_jetson.sh competition force_local_display:=false fullscreen:=false
```

`competition` 脚本会在启动 UI 前执行 X11 显示电源设置，关闭屏保、空白屏和 DPMS 省电息屏，等价于：

```bash
DISPLAY=:0 xset s off
DISPLAY=:0 xset s noblank
DISPLAY=:0 xset -dpms
```

如果现场仍然息屏，先确认当前 X11 状态：

```bash
DISPLAY=:0 xset q
```

其中 `timeout` 应为 `0`，`DPMS is Disabled` 表示已关闭自动息屏。

`competition` 脚本还会默认启动 IBus 拼音输入法。物理屏幕上的系统虚拟键盘仍按屏幕手势调出，项目不再额外启动 Onboard。等价环境变量如下：

```bash
GTK_IM_MODULE=ibus
QT_IM_MODULE=ibus
XMODIFIERS=@im=ibus
ibus-daemon -drx
ibus engine pinyin
```

如果现场不需要中文输入法：

```bash
ENABLE_CHINESE_IME=false ./scripts/run_on_jetson.sh competition
```

如果需要排查输入法：

```bash
ps aux | grep ibus-daemon
ibus engine
ibus list-engine | grep -i pinyin
```

常用参数：

| 参数 | 作用 | 默认值 |
|---|---|---|
| `enable_task_layer` | 是否启动 AI 任务层节点 | `true` |
| `enable_display_ui` | 是否启动显示屏 UI | `true` |
| `enable_system_supervisor` | 是否启动系统控制 supervisor | `true` |
| `task_image_dir` | B-1 任务书图片目录 | `/home/nvidia/ros2_ws/src/ylhb_llm/test_images` |
| `fullscreen` | 是否全屏显示 | `true` |
| `display` | UI 显示目标 | `:0` |
| `force_local_display` | 是否强制使用 `display` 覆盖 SSH DISPLAY | `true` |
| `initial_system_mode` | 初始系统状态 | `ready` |
| `enable_voice` | 是否启用 eMeet Luna 语音输入 | `true` |
| `enable_voice_session` | 是否启用唤醒式连续语音会话 | `true` |
| `enable_capture_voice` | 是否启用按键式单次录音 service | `false` |
| `enable_tts` | 是否启用 eMeet Luna TTS 播报 | `true` |
| `audio_input_device` | 录音设备 | `plughw:CARD=Luna,DEV=0` |
| `audio_output_device` | 播放设备 | `default` |

B-1 图片导入规则：

```text
图片放入 task_image_dir。
支持 .jpg、.jpeg、.png。
目录内没有图片时，UI 显示“未找到任务书图片”。
目录内有多张图片时，UI 显示“目录内存在多张图片，请只保留一张”。
目录内只有一张图片时，UI 显示预览并允许启动 B-1。
```

如果 B-1 显示 `/retail_ai/start_b1_task` 服务未就绪，说明 `retail_task_node` 没有启动或还没完成启动。UI 会先尝试通过 supervisor 启动 AI 任务层并等待服务；仍失败时，检查：

```bash
ros2 service list | grep /retail_ai/start_b1_task
ros2 node list | grep retail_task_node
```

UI 顶部状态栏会显示 `B1服务: 就绪/未就绪`。刚启动比赛总控时，`retail_task_node` 需要几秒钟完成初始化；此时不要立即连续点击 B-1。推荐使用 `./scripts/run_on_jetson.sh competition`，不要只单独运行 `ros2 run ylhb_llm retail_display_ui_node` 后直接点 B-1。

全屏说明：UI 默认使用无边框全屏并设置到主屏幕可用尺寸，目标是占据 Jetson 物理显示器整个屏幕且避开系统面板保留区域。如需窗口化调试：

```bash
./scripts/run_on_jetson.sh competition fullscreen:=false
```

小屏适配说明：UI 会读取主屏幕可用尺寸；当屏幕宽度小于 `1180` 或高度小于 `760` 时，自动启用紧凑布局。紧凑布局会把顶部状态栏拆成多行、缩小按钮/表头/标签间距，并把主内容放入可滚动区域，因此在低分辨率显示屏上即使内容高度超过屏幕，也不会出现窗口内容被全屏边界裁掉后无法访问的问题。

如果显示器或 HDMI 采集器本身开启了过扫描，可能仍会裁掉最外侧几个像素。此时优先在显示器菜单中关闭 overscan/过扫描，或先窗口化验证：

```bash
./scripts/run_on_jetson.sh competition fullscreen:=false
```

### TTS 音频链路调试

需要单独验证播报链路时，直接向统一播报话题
`/retail_ai/say_text` 发布消息。这两条命令只依赖 `voice_output_node` 和 TTS，
不依赖 `retail_task_node`、任务 C 状态机、导航、视觉识别或 service，不能作为正式任务 C 流程。

默认展示商品固定为：

```text
一袋薯片
一瓶营养快线
```

根据 `/home/nvidia/ros2_ws/src/ylhb_llm/config/products.yaml`，当前价格为薯片
3 元、营养快线 6 元，共 2 件商品、总额 9 元。

第一个后台终端指令模拟“完成结算区内的商品信息识别”：

```bash
ros2 topic pub --once /retail_ai/say_text ylhb_interfaces/msg/SayText \
  "{task_id: 'manual_checkout_inspect', priority: 9, interrupt: true, text: '完成结算区内的商品信息识别，结算区域内有一袋薯片和一瓶营养快线。'}"
```

预期播报：

```text
完成结算区内的商品信息识别，结算区域内有一袋薯片和一瓶营养快线。
```

第二个后台终端指令模拟“机器人回到起点区域”：

```bash
ros2 topic pub --once /retail_ai/say_text ylhb_interfaces/msg/SayText \
  "{task_id: 'manual_checkout_total', priority: 9, interrupt: true, text: '已回到起点区域，您购买的2件商品总额为9元。'}"
```

预期播报：

```text
已回到起点区域，您购买的2件商品总额为9元。
```

两个指令彼此独立，可以在同一个后台终端依次执行，也可以分别放在两个终端中。
`interrupt: true` 会终止当前播报并清空等待队列，确保比赛现场立即播放这段语音。
若命令发布成功但没有声音，检查：

```bash
ros2 node list | grep voice_output_node
ros2 topic info /retail_ai/say_text -v
ros2 param get /voice_output_node enabled
ros2 param get /voice_output_node tts_enabled
```

### 系统控制页

UI 的“系统控制”页通过 `/retail_ai/system_command` 向 `system_supervisor_node` 发送 JSON 命令，supervisor 负责启动/停止外部 launch 进程，并通过 `/retail_ai/system_status` 回传状态。

系统控制页提供：

```text
一键启动/停止比赛节点
启动/停止底盘和雷达 bringup
启动/停止手动建图
保存地图
启动/停止导航
启动/停止 ZED
启动/重启感知节点
启动/停止 AI 任务层
软件急停
返回准备状态
```

“一键启动比赛节点”在保分模式下按 `bringup -> zed -> navigation -> llm` 顺序启动比赛栈，不强制启动 YOLO/TensorRT 感知。需要增强模式时使用 `start_yolo_perception:=true` 或手动 `start_perception`。`competition` 启动时 AI 任务层已经内嵌运行，因此 supervisor 会把 `llm` 状态显示为 `embedded`，不会重复启动同名 AI 节点。“一键停止比赛节点”会停止导航、感知、ZED 和底盘/雷达，保留 UI、AI 任务层和语音节点继续运行。

supervisor 支持的命令：

```text
start_bringup / stop_bringup
start_mapping / stop_mapping
start_navigation / stop_navigation / restart_navigation
start_zed / stop_zed
start_perception / stop_perception / restart_perception
start_llm / stop_llm
save_map
emergency_stop
start_competition_stack
stop_competition_stack
return_ready
```

`/retail_ai/system_status` 是 JSON 字符串，核心字段：

```text
bringup/mapping/navigation/zed/perception/llm  # running/stopped/embedded
last_command                                   # 最近处理的命令
success                                        # 最近命令是否成功
message                                        # 最近命令说明或错误原因
timestamp                                      # 状态发布时间戳
```

`save_map` 默认保存到 `~/ros2_ws/src/maps/<map_name>.yaml/.pgm`；直接启动 `navigation.launch.py` 默认优先读取 `~/ros2_ws/maps/my_map.yaml`，缺失时回退到 `~/ros2_ws/src/my_map.yaml`。supervisor 的 `start_navigation` 默认同样使用 `~/ros2_ws/maps/my_map.yaml`；如果要让新地图成为默认导航地图，需要复制到推荐比赛地图路径，或启动导航时覆盖 `map:=...`。

常用系统命令：

```bash
ros2 topic pub --once /retail_ai/system_command std_msgs/msg/String \
  "{data: '{\"command\":\"start_mapping\"}'}"

ros2 topic pub --once /retail_ai/system_command std_msgs/msg/String \
  "{data: '{\"command\":\"save_map\",\"map_name\":\"retail_map_2026\"}'}"

ros2 topic echo /retail_ai/system_status
```

系统模式：

```text
sleep     休眠
ready     比赛准备
mapping   手动建图中
running   任务执行中
fault     异常待处理
```

`mapping` 模式下允许 A-1/手动控制和保存地图，禁止启动 B/C/D 任务。软件急停会发布 `system_mode=fault`、发布“停止”、并向 `/cmd_vel` 连续发布全零 Twist；这不是安全级物理急停，真正急停仍应依赖硬件急停按钮。

### 比赛现场推荐操作顺序

1. 启动 Jetson。
2. 打开显示屏 UI：`./scripts/run_on_jetson.sh competition`。
3. 点击“进入准备”。
4. 如需重新建图，进入“系统控制”页，点击“启动建图”。
5. 手动遥控机器人完成建图。
6. 点击“保存地图”，输入地图名称。
7. 点击“停止建图”。
8. 点击“启动导航”。
9. 点击“启动 ZED”和“启动感知”。
10. 点击“启动 AI 任务层”。
11. 进入任务页面，依次执行 A、B、C、D。
12. 出现异常时点击“软件急停”。
13. 任务完成后点击“任务完成，返回准备”。

---

## 1. 系统架构图

```mermaid
flowchart TB
  classDef hardware fill:#f5f5f5,stroke:#9e9e9e,stroke-width:2px,color:#000
  classDef vendor fill:#fff3e0,stroke:#ffb74d,stroke-width:2px,color:#000
  classDef base fill:#e1f5fe,stroke:#4fc3f7,stroke-width:2px,color:#000
  classDef ai fill:#f3e5f5,stroke:#ce93d8,stroke-width:2px,color:#000

  subgraph HW["硬件物理层"]
    ZLACDRV["ZLAC8015D V4<br/>双轮毂伺服驱动器"]:::hardware
    STM32["STM32 大脑底板<br/>串口底盘回退"]:::hardware
    IMUHW["IMU 陀螺仪<br/>提供姿态感知"]:::hardware
    LIDARHW["RPLidar 激光雷达<br/>构建2D环境轮廓"]:::hardware
    ZEDHW["ZED 2i 双目相机<br/>采集彩图和深度"]:::hardware
  end

  subgraph VENDOR["传感器驱动层"]
    RPLIDAR["rplidar_node<br/>雷达串口数据转 LaserScan"]:::vendor
    ZED["zed_wrapper<br/>发布彩色图和深度图"]:::vendor
  end

  subgraph BASE["导航控制层 ylhb_base"]
    ZLACCTL["zlac8015d_canopen_controller<br/>默认执行 /cmd_vel 并发布 /odom"]:::base
    BASECTL["base_controller<br/>STM32 回退后端"]:::base
    IMUNODE["imu_driver<br/>发布 /imu/data"]:::base
    RSP["robot_state_publisher<br/>发布机器人 TF"]:::base
    EKF["ekf_filter_node<br/>融合底盘和 IMU"]:::base
    SLAM["slam_toolbox<br/>构建2D地图"]:::base
    NAV2["Nav2<br/>定位、规划、避障、控制"]:::base
  end

  subgraph AI["视觉感知层 ylhb_perception"]
    YOLO["yolo_detector_node<br/>TensorRT 加载 yolo26.engine"]:::ai
    LOCALIZER["object_localizer_node.py<br/>检测框加深度估算3D位置"]:::ai
    LEGACY["vision_node.py<br/>旧接口兼容桥"]:::ai
  end

  subgraph LLM["大模型任务层 ylhb_llm + ylhb_interfaces"]
    RETAIL["retail_task_node<br/>图片理解、指令解析、推荐、购物车、结算"]:::ai
    VIN["voice_input_node<br/>eMeet Luna 按钮录音 + ASR"]:::ai
    VOUT["voice_output_node<br/>播报队列 + TTS播放"]:::ai
  end

  ZLACDRV <== "SocketCAN / CANopen" ==> ZLACCTL
  STM32 <== "串口通信" ==> BASECTL
  IMUHW -- "I2C/TTL" --> IMUNODE
  LIDARHW -- "串口数据" --> RPLIDAR
  ZEDHW -- "USB 3.0" --> ZED

  ZLACCTL -- "/odom" --> EKF
  BASECTL -. "base_backend:=stm32 时 /odom" .-> EKF
  IMUNODE -- "/imu/data" --> EKF
  EKF -- "TF: odom -> base_footprint" --> NAV2
  RSP -- "/tf_static" --> NAV2
  
  RPLIDAR -- "/scan" --> SLAM
  RPLIDAR -- "/scan" --> NAV2
  SLAM -- "/map" --> NAV2
  NAV2 -- "/cmd_vel" --> ZLACCTL
  NAV2 -. "base_backend:=stm32" .-> BASECTL

  ZED -- "/zed/.../image" --> YOLO
  YOLO -- "/perception/detections" --> LOCALIZER
  YOLO -- "本地 OpenCV 窗口" --> VIEW(("屏幕查看检测框"))
  YOLO -. "/perception/debug_image 可选" .-> VIEW
  
  ZED -- "/zed/.../depth_registered" --> LOCALIZER
  ZED -- "/zed/.../camera_info" --> LOCALIZER
  
  LOCALIZER -- "/perception/target_pose" --> TASK(("比赛上层逻辑脚本"))
  LOCALIZER -- "/perception/localized_objects" --> RETAIL
  RETAIL -- "/retail_ai/task_event" --> TASK
  TASK -- "/retail_ai/task_status" --> RETAIL
  RETAIL -- "/retail_ai/say_text" --> VOUT
  VIN -- "/retail_ai/text_command" --> RETAIL
  
  YOLO -. "兼容转发" .-> LEGACY
  LOCALIZER -. "兼容转发" .-> LEGACY
```

---

## 2. 工程目录

```text
~/ros2_ws/
├── scripts/
│   ├── install_jetson_dependencies.sh   # 安装 Jetson 依赖
│   ├── build_on_jetson.sh               # 一键编译
│   ├── diagnose_pcan.sh                 # 只读诊断 PEAK PCAN-USB 和内核 CAN 状态
│   ├── install_peak_pcan_safe.sh        # 安全编译/临时加载 PEAK PCAN-USB SocketCAN 驱动
│   ├── install_ch341_safe.sh            # 安全检查/编译/临时加载 CH340/CH341 IMU 串口驱动
│   ├── setup_zlac_can.sh                # 配置 can1/PEAK PCAN-USB SocketCAN 给 ZLAC8015D
│   └── run_on_jetson.sh                 # 常用启动包装
├── docs/
│   └── pcan_peak_setup.md               # PEAK PCAN-USB 安全排查和安装记录
├── src/
│   ├── ylhb_base/                       # 底盘、IMU、雷达编排、建图、导航
│   ├── ylhb_perception/                 # ZED + YOLO26 + 深度定位
│   ├── ylhb_interfaces/                 # 大模型任务层自定义 msg/srv 接口
│   ├── ylhb_llm/                        # 图片理解、语音/文字指令、推荐、结算、播报
│   ├── zed-ros2-wrapper/                # ZED 第三方驱动
│   ├── rplidar_ros-ros2/                # RPLidar 第三方驱动
│   ├── bind_usb.sh                      # 固定 IMU / 雷达串口名
│   ├── my_map.yaml                      # 导航回退地图
│   └── my_map.pgm                       # 导航回退地图图像
├── maps/
│   ├── my_map.yaml                      # navigation.launch.py 优先读取的默认导航地图
│   └── my_map.pgm                       # navigation.launch.py 优先读取的默认导航地图图像
├── build/
├── install/
└── log/
```

`ylhb_base` 主要文件：

```text
src/ylhb_base/
├── launch/bringup.launch.py             # 底层一键启动
├── launch/mapping.launch.py             # 建图启动
├── launch/navigation.launch.py          # 导航启动
├── config/ekf.yaml                      # EKF 参数
├── config/base_kinematics.yaml          # 底盘运动学、限速、轮向、frame 参数
├── config/zlac8015d.yaml                # ZLAC8015D CANopen 通信和看门狗参数
├── config/slam_toolbox_params.yaml      # 建图参数
├── config/nav2_params.yaml              # Nav2 参数
├── src/zlac8015d_canopen_controller.cpp # 默认 ZLAC SocketCAN 底盘后端
├── src/base_controller.cpp              # STM32 串口底盘回退后端
├── src/imu_driver.cpp                   # IMU 节点
└── urdf/ylhb.urdf.xacro                 # 机器人模型与传感器安装位姿
```

`ylhb_perception` 主要文件：

```text
src/ylhb_perception/
├── config/detector.yaml                 # 视觉参数
├── launch/perception.launch.py          # YOLO + 深度定位启动
├── models/yolo26.pt                     # YOLO26 原始训练权重，留给 PC 端训练/导出
├── models/yolo26.onnx                   # PC 端导出的跨平台中间模型
├── models/yolo26.engine                 # Jetson 本机编译出的 TensorRT FP16 推理引擎
├── src/yolo_detector_node.cpp           # C++ TensorRT 实时检测节点，比赛默认入口
├── scripts/export_yolo_trt.py           # Jetson 端 ONNX -> TensorRT engine 编译工具
├── scripts/yolo_detector_node.py        # Python 版检测节点，保留作调试/回退
└── scripts/object_localizer_node.py     # 检测框 + 深度粗定位
```

`ylhb_interfaces` 主要文件：

```text
src/ylhb_interfaces/
├── msg/TaskEvent.msg                    # AI 层发给导航/抓取层的结构化任务事件
├── msg/TaskStatus.msg                   # 导航/抓取层回传执行状态
├── msg/SayText.msg                      # 带 task_id、优先级、打断标记的播报请求
├── msg/VoiceStatus.msg                  # 当前是否正在播报
├── msg/CartState.msg                    # 当前购物车状态和总价
└── msg/RecognizedProduct.msg            # 商品 ID、名称、数量、单价、来源等
```

`ylhb_llm` 主要文件：

```text
src/ylhb_llm/
├── config/products.yaml                 # 16类比赛商品：标准ID、中文名、别名、价格、推荐权重
├── config/llm.yaml                      # 大模型、话题、超时、语音开关等默认参数
├── launch/llm.launch.py                 # 大模型任务层一键启动
└── ylhb_llm/
    ├── retail_task_node.py              # 图片理解、文字/语音指令、推荐、购物车、结算
    ├── basic_motion_command_node.py     # A-1 基本运动文字/语音指令转 /cmd_vel
    ├── qwen_client.py                   # DashScope OpenAI兼容接口封装
    ├── product_catalog.py               # 商品库读取、别名匹配、推荐评分
    ├── voice_input_node.py              # eMeet Luna/ALSA按键录音、ASR、发布文字指令
    └── voice_output_node.py             # 播报队列、TTS、本机播放、语音状态
```

---

## 3. 节点与话题总表

### 3.1 底层与定位

| 节点 | 包 | 订阅 | 发布 | 技术作用 |
|---|---|---|---|---|
| `zlac8015d_canopen_controller` | `ylhb_base` | `/cmd_vel` | `/odom`, `/zlac8015d/status`, `/zlac8015d/fault` | 默认底盘后端；通过 SocketCAN + CANopen 直接控制 ZLAC8015D 双轮毂伺服 |
| `base_controller` | `ylhb_base` | `/cmd_vel` | `/odom` | STM32 串口底盘回退后端，使用 `base_backend:=stm32` 启动 |
| `imu_driver` | `ylhb_base` | 无 | `/imu/data` | 读取 IMU，加速度、角速度、姿态进入 ROS |
| `rplidar_node` | `rplidar_ros` | 无 | `/scan` | 发布 2D 激光雷达扫描 |
| `robot_state_publisher` | `robot_state_publisher` | URDF 参数 | `/tf_static`, `/tf` | 根据 URDF 发布传感器相对车体的坐标关系 |
| `ekf_filter_node` | `robot_localization` | `/odom`, `/imu/data` | `/odometry/filtered`, `/tf` | 融合轮式里程计和 IMU，使 `odom -> base_footprint` 更稳定 |

### 3.2 建图与导航

| 节点 | 包 | 订阅 | 发布 | 技术作用 |
|---|---|---|---|---|
| `slam_toolbox` | `slam_toolbox` | `/scan`, `/tf` | `/map`, `/tf` | 用激光雷达和位姿估计构建 2D 占据栅格地图 |
| `map_server` | `nav2_map_server` | 地图 yaml 参数 | `/map` | 加载已有地图 |
| `amcl` | `nav2_amcl` | `/scan`, `/map`, `/tf` | `/amcl_pose`, `/particle_cloud`, `/tf` | 在已知地图中估计机器人位置 |
| `planner_server` | `nav2_planner` | `/goal_pose`, `/map`, `/tf` | `/plan` | 生成全局路径 |
| `controller_server` | `nav2_controller` | `/plan`, `/tf`, 代价地图 | `/cmd_vel` | 根据路径和障碍物输出速度指令 |

### 3.3 ZED 与 AI 识别

| 节点 | 包 | 订阅 | 发布 | 技术作用 |
|---|---|---|---|---|
| `zed_wrapper` | `zed-ros2-wrapper` | ZED 2i 硬件 | `/zed/zed_node/rgb/color/rect/image`, `/zed/zed_node/depth/depth_registered`, `/zed/zed_node/rgb/color/rect/camera_info` | 发布 RGB 图、深度图、相机内参 |
| `yolo_detector_node` | `ylhb_perception` | `/zed/zed_node/rgb/color/rect/image` | `/perception/detections`, 可选 `/perception/debug_image`，可选本地调试窗口 | C++ TensorRT 直接加载 `yolo26.engine` 做 YOLO26 检测 |
| `object_localizer_node.py` | `ylhb_perception` | `/perception/detections`, 深度图, camera_info | `/perception/localized_objects`, `/perception/target_pose` | 由 2D 检测框和深度图估算目标 3D 坐标 |
| `vision_node.py` | `ylhb_base` | `/perception/detections`, `/perception/target_pose` | `/vision/result`, `/vision/target_pose` | 兼容旧接口 |

### 3.4 大模型任务层

| 节点 | 包 | 订阅/服务输入 | 发布/服务输出 | 技术作用 |
|---|---|---|---|---|
| `retail_task_node` | `ylhb_llm` | `/retail_ai/text_command`, `/retail_ai/system_mode`, `/perception/localized_objects`, `/retail_ai/task_status`, service `/retail_ai/start_b1_task` | `/retail_ai/task_event`, `/retail_ai/say_text`, `/retail_ai/cart` | 比赛任务大脑：任务书图片理解、指令解析、商品推荐、购物车和结算 |
| `basic_motion_command_node` | `ylhb_llm` | `/retail_ai/text_command`, `/retail_ai/system_mode` | `/cmd_vel` | A-1 基本运动控制：前进、后退、左转、右转、停止；不强制播报 |
| `voice_input_node` | `ylhb_llm` | service `/retail_ai/capture_voice`, eMeet Luna/ALSA 录音 | `/retail_ai/text_command` | 按键式单次录音 ASR；默认关闭，UI 可按需调用 |
| `voice_session_node` | `ylhb_llm` | service `/retail_ai/start_voice_session`, `/retail_ai/stop_voice_session`, `/retail_ai/voice_status` | `/retail_ai/voice_command_event`, `/retail_ai/voice_session_status`, `/retail_ai/say_text` | 唤醒式连续语音会话，VAD 分段、ASR、发布语音命令事件 |
| `voice_command_router_node` | `ylhb_llm` | `/retail_ai/voice_command_event`, `/retail_ai/sales_dialogue_status`, `/retail_ai/system_mode`, `/retail_ai/task_status` | `/retail_ai/text_command`, `/retail_ai/say_text` | 把连续语音事件路由到安全指令、A-1、B-2、C 等入口 |
| `voice_output_node` | `ylhb_llm` | `/retail_ai/say_text` | `/retail_ai/voice_status` | 播报队列，支持优先级和打断；可只打印文本，也可启用 TTS 播放 |
| `retail_display_ui_node` | `ylhb_llm` | 任务按钮、系统状态、识别结果、购物车、语音状态 | `/retail_ai/system_mode`, `/retail_ai/system_command`, `/retail_ai/text_command`, `/cmd_vel`, service `/retail_ai/start_b1_task`, `/retail_ai/start_voice_session`, `/retail_ai/stop_voice_session`, `/retail_ai/capture_voice` | 比赛现场显示屏、状态控制台和任务 D 驾驶舱 |
| `system_supervisor_node` | `ylhb_llm` | `/retail_ai/system_command` | `/retail_ai/system_status`, `/retail_ai/system_mode`, `/cmd_vel` | 启动/停止建图、导航、感知、AI任务层，保存地图，集中管理外部进程 |

### 3.5 大模型接口说明

任务 B-1 启动服务：

```text
/retail_ai/start_b1_task
```

类型：`std_srvs/srv/Trigger`

请求：

```text
空。retail_task_node 从 task_image_dir 中读取唯一一张 jpg/jpeg/png 图片。
```

响应：

```text
bool success          # 是否启动成功
string message        # JSON 字符串，包含 task_id、stage、image_path、say_text、error
```

注意：该 service 只触发 B-1 任务入口，不表示 B-1 完成。调用成功后，`retail_task_node` 会先播报图片理解内容，并发布去货架 A 识别的 `/retail_ai/task_event`；到货架并完成识别后，才从真实货架商品中推荐最终商品。

系统模式控制：

```text
/retail_ai/system_mode
```

类型：`std_msgs/msg/String`，取值 `sleep/ready/mapping/running/fault`。发布端和订阅端都使用 `RELIABLE + TRANSIENT_LOCAL + KEEP_LAST + depth=1`，UI 启动后立即发布 `initial_system_mode`。`sleep/mapping/fault` 下任务层忽略普通任务输入，基础运动节点在 `mapping` 下允许手动建图运动，在 `sleep/fault` 下只响应停止。

软件急停/停止运动由 UI 同时执行：

```text
1. 发布 /retail_ai/system_mode = fault
2. 发布 /retail_ai/text_command = "停止"
3. 向 /cmd_vel 连续发布 5 次全零 Twist
```

这不是安全级物理急停；导航取消和机械臂 stop/hold 由后续执行层对接。

文字或语音转写后的指令入口：

```text
/retail_ai/text_command
```

类型：`std_msgs/msg/String`

示例：

```bash
ros2 topic pub --once /retail_ai/text_command std_msgs/msg/String "{data: '来瓶可乐'}"
ros2 topic pub --once /retail_ai/text_command std_msgs/msg/String "{data: '一共多少钱'}"
```

结构化任务事件：

```text
/retail_ai/task_event
```

类型：`ylhb_interfaces/msg/TaskEvent`

核心字段：

```text
task_id        # 幂等任务ID，导航/抓取层回传状态时必须带回
intent         # pick_item / checkout / unknown
item_id        # 商品标准ID，例如 water_nongfu
item_name      # 商品中文名，例如 农夫山泉矿泉水
destination    # checkout / shelf / start 等目标阶段
confidence     # AI/规则综合置信度
source         # image / voice / text / checkout
requires_ack   # 是否需要执行层回传 /retail_ai/task_status
raw_json       # 调试用原始 JSON，不作为跨节点核心字段
```

常见事件流：

```text
B-1：inspect_shelf_for_recommendation -> 执行层回传 inspect_shelf succeeded -> pick_item
B-2：pick_item；语音来源默认需要先确认推荐，再发布取货事件
C：checkout -> 执行层回传 checkout_inspect succeeded -> return_start -> 执行层回传 return_start succeeded
```

执行状态回传：

```text
/retail_ai/task_status
```

类型：`ylhb_interfaces/msg/TaskStatus`

导航/抓取层执行后发布：

```text
task_id     # 必须和 task_event 中一致
stage       # navigate_to_shelf / grasp / navigate_to_checkout / place / return_start
status      # started / succeeded / failed / rejected
reason      # 失败或拒绝原因
```

如果 `retail_task_node` 收到 `succeeded`，才把对应商品加入购物车；收到 `failed/rejected`，只播报失败原因，不更新购物车。

播报请求：

```text
/retail_ai/say_text
```

类型：`ylhb_interfaces/msg/SayText`

核心字段：

```text
task_id      # 播报关联任务
priority     # 数字越大越优先播放
interrupt    # true 时清空等待队列
text         # 要播报的中文文本
```

语音状态：

```text
/retail_ai/voice_status
```

类型：`ylhb_interfaces/msg/VoiceStatus`

内容：

```text
speaking           # 当前是否正在播报
current_task_id    # 正在播报的任务ID
```

购物车状态：

```text
/retail_ai/cart
```

类型：`ylhb_interfaces/msg/CartState`

`CartState` 中的商品使用 `RecognizedProduct`，包含标准商品 ID、名称、类别、数量、单价、置信度、来源任务 ID、来源、检测框和调试 JSON。总价由本地代码按 `products.yaml` 计算，不让大模型直接决定最终金额。

销售对话状态：

```text
/retail_ai/sales_dialogue_status
```

类型：`std_msgs/msg/String`，内容为 JSON。`retail_task_node` 发布，UI 和 `voice_command_router_node` 订阅。用于 B-2 销售对话，包含 `active/state/primary_product_name/related_products/pending_product_name/waiting_for/last_reply` 等字段。连续语音模式下，明确商品或需求型购物都会先进入待确认状态；用户确认后才发布 `pick_item` 取货事件。

连续语音事件：

```text
/retail_ai/voice_command_event
```

类型：`std_msgs/msg/String`，内容为 JSON。`voice_session_node` 发布，字段包括 `source/session_id/utterance_id/text/raw_asr_text/awakened/contains_wake_phrase/confidence/timestamp`。`voice_command_router_node` 会转发为 `/retail_ai/text_command` JSON，并附加 `route` 字段。

连续语音状态：

```text
/retail_ai/voice_session_status
```

类型：`std_msgs/msg/String`，内容为 JSON。核心字段包括 `enabled/state/wake_phrase/awakened/session_id/waiting_for/is_tts_playing/is_recording/asr_fail_count/last_asr_text/last_published_text/last_error/last_update_time`。

语音 service：

```text
/retail_ai/capture_voice          # std_srvs/srv/Trigger，按键式单次录音 ASR
/retail_ai/start_voice_session    # std_srvs/srv/Trigger，开启唤醒式连续语音
/retail_ai/stop_voice_session     # std_srvs/srv/Trigger，关闭唤醒式连续语音
```

### 3.6 发布/订阅内容细化说明

这一节解释上面表格中每个核心话题“里面是什么、谁用它、比赛调试时怎么看”。

#### 3.6.1 底盘后端：`zlac8015d_canopen_controller` / `base_controller`

默认底盘后端是 `zlac8015d_canopen_controller`，Jetson 通过 PEAK PCAN-USB 暴露出的 SocketCAN `can1` 直接和 ZLAC8015D V4 CANopen 驱动器通信。旧 `base_controller` 保留为 STM32 串口回退方案：

```bash
# 默认 ZLAC SocketCAN 后端
ros2 launch ylhb_base bringup.launch.py base_backend:=zlac

# STM32 串口回退
ros2 launch ylhb_base bringup.launch.py base_backend:=stm32 base_port:=/dev/ttyS1
```

ZLAC 参数文件：

```text
config/base_kinematics.yaml  # 轮半径、轮距、最大线/角速度、左右轮方向、frame
config/zlac8015d.yaml        # CAN 接口、node_id、SDO 超时、看门狗、反馈/故障检查频率
```

当前现场默认 CAN 接口：

```text
can0  # Jetson 板载 mttcan，不接 ZLAC8015D 底盘链路
can1  # PEAK PCAN-USB，已验证为 ZLAC8015D 底盘链路
```

PCAN-USB 验证结论：

```text
lsusb 能看到 0c72:000c PEAK System PCAN-USB
pcan 模块为 PEAK Linux driver 8.15.2，netdev/SocketCAN 模式
ip -details link show can1 显示 can1 UP、ERROR-ACTIVE、bitrate 500000
candump -tz can1 能收到 ZLAC8015D 上电心跳：701#00
```

底盘上线前必须先保证 `can1` 是 500k 并处于 UP：

```bash
cd ~/ros2_ws
./scripts/setup_zlac_can.sh can1 500000
ip -details link show can1
candump -tz can1
```

`candump` 看到 `701#00` 后，再启动默认 ZLAC 后端。否则先排查 PEAK 驱动、USB-CAN 线、CANH/CANL、终端电阻、ZLAC 上电和波特率。

订阅：

```text
/cmd_vel                   # 接收外部线速度、角速度控制底层电机的订阅话题
```

消息类型：`geometry_msgs/msg/Twist`

内容含义：

```text
linear.x    # 前进/后退线速度，单位 m/s
angular.z   # 原地左转/右转角速度，单位 rad/s
```

谁会发布：

```text
Nav2 controller_server       # 自动导航时发布
teleop_twist_keyboard        # 手动键盘遥控时发布
上层比赛任务逻辑             # 需要直接控制底盘时发布
```

发布：

```text
/odom                      # 由底盘编码器积分推算出的基础轮式里程计发布话题
/zlac8015d/status          # ZLAC 后端状态、心跳、实际左右轮 rpm；默认约 1Hz
/zlac8015d/fault           # ZLAC 非零故障码；不会循环自动清故障
```

消息类型：`nav_msgs/msg/Odometry`

内容含义：

```text
header.frame_id = odom
child_frame_id  = base_footprint
pose            # 底盘根据轮速积分得到的位置和姿态
twist           # 当前线速度和角速度
```

谁会订阅：

```text
ekf_filter_node      # 和 IMU 融合，得到更稳定的里程计
Nav2 / SLAM          # 间接使用 odom 相关 TF 和位姿估计
调试工具             # 用于观察底盘反馈是否正常
```

检查命令：

```bash
ros2 topic echo /cmd_vel --once
ros2 topic echo /odom --once
ros2 topic echo /zlac8015d/status
ros2 topic echo /zlac8015d/fault
```

比赛调试重点：

```text
如果 /cmd_vel 有数据但 /odom 不变，默认优先查 CAN 接口、ZLAC 使能、故障码和电机反馈。
使用 base_backend:=stm32 时，再查底盘串口、STM32、电机反馈。
如果 /odom 跳变，导航和建图都会受影响。
```

#### 3.6.2 `imu_driver`

`imu_driver` 把 IMU 串口数据转换成 ROS 标准 IMU 消息。

当前现场 IMU 是 WIT 协议串口模块，实测输出为 `9600` 波特率，原始帧包含：

```text
0x55 0x51  # 加速度
0x55 0x52  # 角速度
0x55 0x53  # 姿态角
```

默认启动参数：

```text
serial_port:=/dev/robot_imu
baud_rate:=9600
auto_detect_baud:=true
configure_on_start:=false
```

`auto_detect_baud` 会在需要时尝试 `115200/9600/57600/38400/19200`，确认能解析 WIT 帧后再进入正常读取。`configure_on_start` 默认关闭，不在每次 ROS 启动时向 IMU 写入解锁、改波特率、保存等配置命令；只有明确需要重新配置 IMU 模块时才手动打开。

发布：

```text
/imu/data                  # 以极高频率发布角速度、加速度、姿态四元数的 IMU 话题
```

消息类型：`sensor_msgs/msg/Imu`

内容含义：

```text
orientation          # 姿态四元数
angular_velocity     # 角速度，主要关注 z 轴 yaw 角速度
linear_acceleration  # 线加速度
covariance           # 传感器噪声估计，EKF 会使用
```

谁会订阅：

```text
ekf_filter_node      # 与 /odom 融合
调试工具             # 检查 IMU 是否稳定、有无漂移
```

检查命令：

```bash
ros2 topic echo /imu/data --once
ros2 topic hz /imu/data
ros2 topic info /imu/data --no-daemon
```

比赛调试重点：

```text
IMU yaw 方向如果反了，机器人转向估计会错。
IMU 数据剧烈跳动，EKF 输出也会不稳定。
如果 Foxglove 能看到 /imu/data，但 ros2 topic echo 偶发抓不到，先用 --no-daemon 查真实 ROS 图，避免 daemon 缓存误判。
如果 /dev/robot_imu 存在但没有 /imu/data，先检查 imu_driver 是否启动，再确认波特率是否为 9600。
```

#### 3.6.3 `rplidar_node`

`rplidar_node` 把 RPLidar 激光扫描转换成 ROS 标准雷达消息。

发布：

```text
/scan                      # 发布激光雷达 360° 环境切面距离测算数据的的话题
```

消息类型：`sensor_msgs/msg/LaserScan`

内容含义：

```text
angle_min / angle_max        # 扫描角度范围
angle_increment              # 每个点之间的角度间隔
range_min / range_max        # 有效测距范围
ranges                       # 每个角度方向上的距离数组
intensities                  # 反射强度，可选
header.frame_id = laser_link # 雷达坐标系
```

谁会订阅：

```text
slam_toolbox     # 建图
amcl             # 已知地图下定位
Nav2 costmap     # 障碍物避障
```

检查命令：

```bash
ros2 topic echo /scan --once
ros2 topic hz /scan
```

比赛调试重点：

```text
/scan 没有数据，建图和导航都无法工作。
laser_link 的 TF 如果安装角度不对，地图会歪，导航也会偏。
```

#### 3.6.4 `robot_state_publisher`

`robot_state_publisher` 不直接读取硬件，它读取 URDF，把机器人结构发布到 TF。

输入：

```text
robot_description 参数
```

来源：

```text
~/ros2_ws/src/ylhb_base/urdf/ylhb.urdf.xacro
```

发布：

```text
/tf_static                 # 广播机器人自身零部件不变的固定物理距离安装点 (如 base_link 到 radar_link)
/tf                        # 广播机器人移动时随时在变的外部坐标系参照系变换
```

内容含义：

```text
base_footprint -> laser_link               # 雷达安装位置
base_footprint -> imu_link                 # IMU 安装位置
base_footprint -> zed_left_camera_frame... # 相机安装位置，后续可继续完善
```

谁会使用：

```text
slam_toolbox       # 需要知道雷达相对车体的位置
Nav2               # 需要完整 TF 树
object_localizer   # 后续如果要把相机坐标目标转换到车体/地图坐标，需要 TF
```

检查命令：

```bash
ros2 run tf2_tools view_frames
```

比赛调试重点：

```text
TF 树断了，建图/导航/定位都会出问题。
雷达或相机的实际安装位置变了，必须同步改 URDF。
```

#### 3.6.5 `ekf_filter_node`

`ekf_filter_node` 负责融合轮式里程计和 IMU。

订阅：

```text
/odom
/imu/data
```

发布：

```text
/odometry/filtered         # 经卡尔曼滤波消除误差后提供更平滑平稳表现的增强里程计
/tf                        # 发布包含增强状态计算得出的 Odom 等相关坐标转换
```

发布内容含义：

```text
/odometry/filtered
  融合后的里程计，通常比纯轮速 /odom 更稳定。

/tf
  主要发布 odom -> base_footprint 的动态坐标变换。
```

谁会使用：

```text
slam_toolbox
Nav2
AMCL
TF 查询工具
```

检查命令：

```bash
ros2 topic echo /odometry/filtered --once
ros2 run tf2_ros tf2_echo odom base_footprint
```

比赛调试重点：

```text
EKF 输出不稳，建图会弯，导航会飘。
如果 /odom 和 /imu/data 时间戳异常，EKF 可能融合失败。
```

#### 3.6.6 `slam_toolbox`

`slam_toolbox` 是建图核心。

订阅：

```text
/scan
/tf
```

发布：

```text
/map                       # SLAM 算法拼图输出的代表场地的全局 2D 占据栅格地图
/tf                        # SLAM 定位闭环后发布的 /map 坐标对 /odom 的补偿链接
```

发布内容含义：

```text
/map
  nav_msgs/msg/OccupancyGrid
  2D 占据栅格地图。
  白色通常表示可通行，黑色表示障碍，灰色表示未知区域。

/tf
  map -> odom
  表示地图坐标系和里程计坐标系之间的修正关系。
```

谁会使用：

```text
RViz / Foxglove       # 可视化地图
map_saver_cli         # 保存地图
Nav2                  # 如果边建图边导航，会使用地图和 TF
```

检查命令：

```bash
ros2 topic echo /map --once
ros2 run tf2_ros tf2_echo map odom
```

比赛调试重点：

```text
/map 质量决定后续导航质量。
建图时车速要慢，转弯要稳，避免地图重影和弯曲。
```

#### 3.6.7 Nav2：`map_server` / `amcl` / `planner_server` / `controller_server`

Nav2 是导航核心，不是单个节点，而是一组节点协同工作。

`map_server` 发布：

```text
/map
```

内容：

```text
从 my_map.yaml 和 my_map.pgm 读取出来的静态地图。
```

`amcl` 订阅：

```text
/scan
/map
/tf
```

`amcl` 发布：

```text
/amcl_pose                 # 粒子滤波算法判断后认定的场内大概率坐标和朝向
/particle_cloud            # 可视化表现粒子群在寻找定位过程中的收敛置信云团
/tf                        # 纠正并发送 map 与 odom 间的实时误差对齐参数
```

内容：

```text
/amcl_pose
  机器人在 map 坐标系下的估计位置。

/particle_cloud
  AMCL 粒子云，用于观察定位是否收敛。

/tf
  map -> odom，用于把里程计坐标修正到地图坐标。
```

`planner_server` 发布：

```text
/plan                      # 导航服务根据障碍物计算出的一条从起点到终点的全局通行轨迹
```

内容：

```text
从当前位置到目标点的全局路径。
```

`controller_server` 发布：

```text
/cmd_vel                   # 接收外部线速度、角速度控制底层电机的订阅话题
```

内容：

```text
最终给底盘执行的速度指令。
```

检查命令：

```bash
ros2 topic echo /amcl_pose --once
ros2 topic echo /plan --once
ros2 topic echo /cmd_vel
```

比赛调试重点：

```text
有 /plan 但没有 /cmd_vel：多半是局部控制器、代价地图或 lifecycle 状态问题。
有 /cmd_vel 但车不动：多半是底盘串口或 base_controller 问题。
```

#### 3.6.8 `zed_wrapper`

`zed_wrapper` 是 ZED 2i 的 ROS2 驱动。

发布：

```text
/zed/zed_node/rgb/color/rect/image         # ZED 2i 左目主镜头截取且畸变纠正的彩色图像流
/zed/zed_node/rgb/color/rect/camera_info   # 附带出厂级内参矩阵的相机信息
/zed/zed_node/depth/depth_registered       # 与彩色图像完全对齐的高精度深度距离图
/zed/zed_node/point_cloud/cloud_registered # 相机解算出的三维空间点云数据
/zed/zed_node/imu/data                     # 相机内部自带的高频高精 IMU 传感器数据
/zed/zed_node/pose                         # 相机自带空间测算视觉里程计输出的位姿
```

核心内容：

```text
/zed/zed_node/rgb/color/rect/image
  sensor_msgs/msg/Image
  YOLO26 的实时输入图像。
  当前实测分辨率为 960x540，encoding 可能是 bgra8。

/zed/zed_node/rgb/color/rect/camera_info
  sensor_msgs/msg/CameraInfo
  RGB 相机内参，包含 fx/fy/cx/cy。

/zed/zed_node/depth/depth_registered
  sensor_msgs/msg/Image
  与 RGB 对齐的深度图。
```

谁会订阅：

```text
yolo_detector_node          # 订阅 RGB 图像，C++ TensorRT 实时检测
object_localizer_node.py    # 订阅深度图和相机内参
```

检查命令：

```bash
ros2 topic hz /zed/zed_node/rgb/color/rect/image
ros2 topic echo /zed/zed_node/rgb/color/rect/camera_info --once
ros2 topic hz /zed/zed_node/depth/depth_registered
ros2 run rqt_image_view rqt_image_view /zed/zed_node/rgb/color/rect/image
```

注意：

```text
ros2 topic echo 图像时看到 data=Uint8Array(...) 是正常现象。
RGB 图像内容可用 rqt_image_view 或 Foxglove 看；YOLO 检测效果优先用本地 OpenCV 调试窗口看。
不要在 Foxglove/rqt 中订阅深度图的 `/compressed` 话题，32FC1 深度图不支持 JPEG compressed。
```

#### 3.6.9 `yolo_detector_node`

`yolo_detector_node` 是实时 2D 目标检测节点。比赛默认入口是 C++ 可执行文件，不再通过 Python/Ultralytics 跑实时图像流。

订阅：

```text
/zed/zed_node/rgb/color/rect/image
```

输入内容：

```text
ZED 2i RGB 图像。
节点内部通过 cv_bridge 转成 OpenCV 图像，OpenCV 做 letterbox 预处理，再用 TensorRT Runtime 直接加载 yolo26.engine 推理。
```

发布：

```text
/perception/detections     # 高级视觉 AI 检测完毕后用 JSON 打包的所有场上目标信标
/perception/debug_image    # 可选 ROS2 调试图。默认不依赖它看效果，避免 DDS/Foxglove/rqt 影响时效
本地 OpenCV 窗口       # 推荐调试方式。show_debug_window:=true 时直接弹窗显示检测框
```

`/perception/detections` 内容：

```text
std_msgs/msg/String
内容是 JSON 字符串。
```

JSON 字段：

```text
header.stamp       # 图像时间戳
header.frame_id    # 图像坐标系，当前通常是 zed_left_camera_frame_optical
backend            # 配置中的后端标识，比赛部署为 tensorrt
actual_backend     # 节点根据模型后缀识别出的实际后端，.engine 对应 tensorrt
model_path         # 当前模型路径
detections         # 检测框数组
```

每个 detection：

```text
class_id       # 模型输出的类别编号
class_name     # 根据 detector.yaml 的 class_names 翻译；未配置时为 class_id 字符串
confidence     # 置信度
bbox_xyxy      # 检测框左上角/右下角像素坐标
bbox_center    # 检测框中心点像素坐标
bbox_size      # 检测框宽高
```

`/perception/debug_image` 内容：

```text
sensor_msgs/msg/Image
可选 ROS2 带框调试图。默认关闭；本机调试优先用 OpenCV 窗口。
```

检查命令：

```bash
ros2 topic echo /perception/detections --once
```

调试看效果优先使用：

```bash
ros2 launch ylhb_perception perception.launch.py \
  model_path:=/home/nvidia/ros2_ws/src/ylhb_perception/models/yolo26.engine \
  publish_debug_image:=false \
  show_debug_window:=true \
  debug_window_max_hz:=15.0
```

只有需要远程录制或给 Foxglove 转发时，才打开 `/perception/debug_image`。

比赛调试重点：

```text
ROS 不决定识别类别，类别由 YOLO 模型 names 决定。
如果一直识别成 refrigerator、tv、sheep，说明模型类别表是 COCO 80 类，不是比赛目标模型。
C++ 节点不会自动读取 .pt 的 names；需要可读类别名时，在 detector.yaml 的 class_names 里按 class_id 顺序填写。
```

#### 3.6.10 `object_localizer_node.py`

`object_localizer_node.py` 把 2D 检测框粗略转换成 3D 目标点。

订阅：

```text
/perception/detections
/zed/zed_node/depth/depth_registered
/zed/zed_node/rgb/color/rect/camera_info
```

处理逻辑：

```text
1. 读取 YOLO 检测框。
2. 取检测框中心点像素坐标。
3. 在 ZED 深度图中读取中心点附近深度。
4. 使用 camera_info 中的 fx/fy/cx/cy 反投影到相机坐标系。
5. 发布目标 3D 粗定位结果。
```

发布：

```text
/perception/localized_objects  # 把 2D 上的物品切入深度图求算出 3D 绝对物理空间相对位姿的目标集合
/perception/target_pose        # 单独取出的场内首个有效被跟踪猎物的专属空间指向三维坐标系
```

`/perception/localized_objects` 内容：

```text
std_msgs/msg/String
JSON 字符串，包含每个目标的类别、置信度、2D 框和相机坐标系下的 x/y/z。
```

`/perception/target_pose` 内容：

```text
geometry_msgs/msg/PoseStamped
默认发布第一个有效目标的位置。
frame_id 当前为 zed_left_camera_frame_optical。
```

检查命令：

```bash
ros2 topic echo /perception/localized_objects --once
ros2 topic echo /perception/target_pose --once
```

比赛调试重点：

```text
当前 3D 定位是基础版本，只取检测框中心附近深度。
如果目标边缘深度不准，3D 点会跳。
后续可改成检测框区域内深度中位数、类别筛选、目标跟踪。
```

#### 3.6.11 `vision_node.py`

`vision_node.py` 是旧接口兼容桥，不是主视觉节点。

订阅：

```text
/perception/detections
/perception/target_pose
```

发布：

```text
/vision/result             # 这是为过去老旧的系统模块留下来的兼容器：发布图像物体分类数据
/vision/target_pose        # 这是为过去代码保留的兼容器：给出目标相较于车身的方向与距离等三维信息
```

作用：

```text
如果旧比赛任务代码还订阅 /vision/result 或 /vision/target_pose，
可以临时启动这个桥接节点，不需要改旧代码。
新代码建议直接订阅 /perception/*。
```

启动：

```bash
ros2 run ylhb_base vision_node.py
```

---

## 4. 建图流程

建图是比赛前最重要的基础工作。地图质量会直接影响导航稳定性。

### 4.1 技术原理

本项目使用 `slam_toolbox` 做 2D 激光建图。

建图依赖三类信息：

```text
1. /scan
   RPLidar 发布的激光雷达扫描，用于观察墙、障碍物和场地边界。

2. odom -> base_footprint
   EKF 融合后的机器人短时间运动估计，用于告诉 SLAM 机器人大概怎么移动。

3. base_footprint -> laser_link
   URDF 发布的雷达安装位姿，用于把雷达数据转换到机器人坐标系。
```

建图数据流：

```mermaid
flowchart LR
  RPLidar[/scan/] --> SLAM[slam_toolbox]
  ODOM[odom->base_footprint TF] --> SLAM
  URDF[base_footprint->laser_link TF] --> SLAM
  SLAM --> MAP[/map/]
  SLAM --> TF[map->odom TF]
  MAP --> SAVE[map_saver_cli 保存 my_map]
```

### 4.2 启动建图

终端 1，启动底层：

```bash
cd ~/ros2_ws
source install/setup.bash
ros2 launch ylhb_base bringup.launch.py
```

终端 2，启动建图：

> **🗺️ 核心指令：执行环境建图操作**

```bash
cd ~/ros2_ws
source install/setup.bash
# 启动 SLAM 节点 (默认使用 slam_toolbox)。
# 它会根据小车底盘移动的里程计 (odom) 与 激光雷达数据 (scan) 绘制地图
ros2 launch ylhb_base mapping.launch.py
```

终端 3，键盘遥控：

```bash
source /opt/ros/humble/setup.bash

ros2 run teleop_twist_keyboard teleop_twist_keyboard \
  --ros-args \
  -p speed:=0.15 \
  -p turn:=0.25
```

其中 `speed` 是线速度，单位 `m/s`；`turn` 是角速度，单位 `rad/s`。

### 4.3 建图时怎么开车

建图时不要乱跑，建议按比赛场地边界缓慢走一圈：

```text
1. 先沿场地外圈慢速移动。
2. 再补充中间区域。
3. 转弯要慢，避免里程计和雷达匹配跳变。
4. 不要频繁高速原地旋转。
5. 每走一段观察 /map 是否变形。
```

### 4.4 保存地图

> **💾 核心指令：持久化保存场地地图**

```bash
# 进入你期望存储地图的数据目录
cd ~/ros2_ws/src
source ~/ros2_ws/install/setup.bash

# 调用 Nav2 提供的终端保存工具
# 参数讲解：
#   -f my_map: 代表你要保存的文件基础名（File）。系统会自动生成对应的 my_map.yaml (元数据表) 和 my_map.pgm (二维栅格画布)
#   save_map_timeout:=10.0: 等待 /map 的最长时间，避免默认 2 秒在当前 SLAM 发布节奏下偶发超时
ros2 run nav2_map_server map_saver_cli -f my_map --ros-args -p save_map_timeout:=10.0
```

输出：

```text
~/ros2_ws/src/my_map.yaml
~/ros2_ws/src/my_map.pgm
```

UI 的“保存地图”按钮走 `system_supervisor_node` 的 `save_map` 命令，默认保存到：

```text
~/ros2_ws/src/maps/<map_name>.yaml
~/ros2_ws/src/maps/<map_name>.pgm
```

移动端 `/api/debug/mapping/save` 也走同一类 `map_saver_cli` 保存逻辑。两个入口都已统一设置 `save_map_timeout:=10.0`，失败时会保留 `map_saver_cli` 的输出，便于区分 `/map` 超时、路径权限、目录不存在等问题。

当前仓库回退地图 `~/ros2_ws/src/my_map.yaml/.pgm` 已更新为实机保存结果，地图尺寸 `195 x 333`，分辨率 `0.05 m/pix`。直接启动 `navigation.launch.py` 时会优先使用 `~/ros2_ws/maps/my_map.yaml`，该文件不存在才回退到 `~/ros2_ws/src/my_map.yaml`。

注意：保存目录和导航默认地图是两个概念。比赛推荐导航地图是 `~/ros2_ws/maps/my_map.yaml`，`~/ros2_ws/src/my_map.yaml` 只作为兼容回退。如果要使用 UI 保存的新地图，需要复制成推荐默认地图，或启动导航时显式传 `map:=~/ros2_ws/src/maps/<map_name>.yaml`。

### 4.5 建图验收标准

地图可用于比赛前，至少满足：

```text
1. 墙体边界不明显弯曲。
2. 闭环后地图没有大幅错位。
3. 小车回到起点时，地图位置能对上。
4. 雷达障碍物在 RViz/Foxglove 中和实际障碍位置基本一致。
5. 保存后的 my_map.yaml 能被 navigation.launch.py 正常加载。
```

### 4.6 建图常见问题

地图弯曲：

```text
常见原因：车速太快、轮式里程计不准、雷达安装 TF 不准。
处理：降低速度，检查 ylhb.urdf.xacro 中 laser_link 位姿。
```

地图重影：

```text
常见原因：回环匹配失败或机器人转弯太快。
处理：沿边界慢速走，避免快速原地旋转。
```

没有 `/map`：

```bash
ros2 topic list | grep map
ros2 topic echo /scan --once
ros2 run tf2_tools view_frames
```

---

## 5. 导航流程

导航是比赛执行阶段的核心。它依赖一张稳定地图和正确的 TF 树。

### 5.1 技术原理

Nav2 导航链路：

```text
地图加载：
  map_server 读取 my_map.yaml，发布 /map

定位：
  AMCL 使用 /scan 和 /map 估计机器人在地图中的位置

规划：
  planner_server 根据目标点生成全局路径 /plan

控制：
  controller_server 根据路径、局部代价地图和当前位姿发布 /cmd_vel

执行：
  base_controller 接收 /cmd_vel，通过串口控制 STM32 底盘
```

导航数据流：

```mermaid
flowchart LR
  MAP[my_map.yaml] --> MAPSERVER[map_server]
  MAPSERVER --> MAPTOPIC[/map/]
  SCAN[/scan/] --> AMCL[amcl]
  MAPTOPIC --> AMCL
  TF[/tf/] --> AMCL
  AMCL --> MAPODOM[map->odom TF]
  GOAL[/goal_pose/] --> PLANNER[planner_server]
  MAPTOPIC --> PLANNER
  PLANNER --> PLAN[/plan/]
  PLAN --> CONTROLLER[controller_server]
  CONTROLLER --> CMD[/cmd_vel/]
  CMD --> BASE[base_controller]
```

### 5.2 启动导航

终端 1，启动底层：

```bash
cd ~/ros2_ws
source install/setup.bash
ros2 launch ylhb_base bringup.launch.py
```

终端 2，启动导航：

> **🧭 核心指令：启动 Nav2 路径规划和定位**

```bash
cd ~/ros2_ws
source install/setup.bash
# 启动 Nav2 的导航栈，这会自动启动 AMCL(自动蒙特卡洛定位) 以及局部/全局代价地图
# 比赛默认从建图起点附近启动，AMCL 会先使用地图原点 (0, 0, 0) 初始化
# 系统会依据保存的 my_map 并计算最近的可行驶路线
ros2 launch ylhb_base navigation.launch.py
```

默认地图：

```text
~/ros2_ws/maps/my_map.yaml
```

如果 `~/ros2_ws/maps/my_map.yaml` 不存在，`navigation.launch.py` 会回退到：

```text
~/ros2_ws/src/my_map.yaml
```

指定其他地图：

```bash
ros2 launch ylhb_base navigation.launch.py map:=/绝对路径/地图.yaml
```

### 5.3 导航前检查

```bash
# 地图是否发布
ros2 topic echo /map --once

# 雷达是否发布
ros2 topic echo /scan --once

# 里程计是否发布
ros2 topic echo /odom --once

# TF 是否完整
ros2 run tf2_tools view_frames

# AMCL 是否已发布定位；默认原点启动时无需人工初始位姿
ros2 topic echo /amcl_pose --once
```

关键 TF 链路：

```text
map -> odom -> base_footprint -> laser_link
map -> odom -> base_footprint -> zed_left_camera_frame_optical
```

### 5.4 比赛导航注意点

```text
1. 建图起点和比赛启动点尽量一致。
2. 默认按建图原点初始化；如果机器人不在建图起点附近，先在 RViz/Foxglove 发布 /initialpose 覆盖。
3. 小车上电后先让 AMCL 稳定。
4. 如果定位不准，先原地缓慢旋转一圈，让雷达特征帮助粒子收敛。
5. Foxglove/RViz 发布 `/goal_pose` 时 `header.frame_id` 必须是 `map`。
6. 目标点不要贴墙，给局部规划器留出安全距离。
7. 若 /cmd_vel 有输出但车不动，优先检查底盘串口和 base_controller。
```

### 5.5 定位贴合调试

定位贴合问题先按几何关系排查，不要一开始就硬调 AMCL 参数：

```text
1. 先确认 bringup 已启动，/odom、/scan、/tf 都在发布；单独启动 navigation.launch.py 没有底层 odom，Nav2 会一直等 TF。
2. 机器人静止时，在 Foxglove/RViz 同时显示 /map、/scan、/particle_cloud。
3. 如果机器人不在建图原点附近，先发布 /initialpose；默认原点位姿只适合原点附近开局。
4. 再检查 /scan 与 /map 墙线是否像一个刚体一样整体错位。
5. 如果整体旋转错，优先校准 ylhb.urdf.xacro 里的 laser_link yaw。
6. 如果整体前后错，优先校准 laser_link x。
7. 如果整体左右错，优先校准 laser_link y。
8. 雷达外参基本正确后，再校准 wheel_radius 和 wheel_track，减少里程计累计误差。
9. 最后重新建图并用新图导航，避免拿旧地图硬调 AMCL。
```

判断顺序：

```text
/scan 静止时就和墙线对不上：优先查 laser_link 外参或地图质量。
/particle_cloud 在人工初始位姿附近不收敛：查初始位姿、雷达模型参数和地图是否匹配。
运动后才逐渐偏：优先查 wheel_radius、wheel_track、IMU/EKF 和底盘打滑。
```

`Starting point in lethal space` 排查顺序：

```text
1. 确认加载的是最新比赛地图，优先使用 ~/ros2_ws/maps/my_map.yaml。
2. 如果当前位置偏离建图原点，重新发布 /initialpose，让 /scan 与 /map 墙线贴合后再发目标点。
3. 在 Foxglove/RViz 叠加 /scan、/map、/particle_cloud，确认定位没有整体平移或旋转偏差。
4. 确认 global_costmap 只启用 static_layer 和 inflation_layer，没有误加 obstacle_layer。
5. 再检查 footprint 和 footprint_padding 是否过大，避免起点被车体外廓直接判为碰撞。
```

只有再次出现 TF future extrapolation 时，再考虑 EKF 的 `transform_time_offset` 和 `transform_timeout`。

### 5.6 导航常见问题

小车在地图里位置飘：

```text
检查 AMCL、/scan、TF、地图是否一致。
雷达安装角度错误会导致定位明显偏。
```

规划出路径但不动：

```bash
ros2 topic echo /cmd_vel
ros2 topic echo /odom --once
```

有 `/cmd_vel` 但车不动，查底盘串口。  
没有 `/cmd_vel`，查 Nav2 lifecycle、代价地图和目标点。

---

## 6. AI 识别流程

AI 识别用于比赛任务目标检测。当前链路已经跑通：ZED 图像能进入 YOLO，YOLO 能输出检测结果。

### 6.1 技术原理

视觉分两步：

```text
1. 2D 检测
   ZED RGB 图像 -> YOLO26 -> 检测框、类别、置信度

2. 深度粗定位
   检测框中心点 + ZED 深度图 + 相机内参 -> 相机坐标系下的 3D 点
```

视觉数据流：

```mermaid
flowchart LR
  RGB[/zed/zed_node/rgb/color/rect/image/] --> YOLO[yolo_detector_node]
  YOLO --> DET[/perception/detections/]
  YOLO --> WIN[本地 OpenCV 调试窗口]
  YOLO -. 可选 .-> DBG[/perception/debug_image/]
  DET --> LOC[object_localizer_node]
  DEPTH[/zed/zed_node/depth/depth_registered/] --> LOC
  INFO[/zed/zed_node/rgb/color/rect/camera_info/] --> LOC
  LOC --> OBJ[/perception/localized_objects/]
  LOC --> POSE[/perception/target_pose/]
```

### 6.2 PC 端导出优化 ONNX

当前部署原则：PC 端负责训练并导出 ONNX，Jetson 端执行一次 ONNX 到 TensorRT engine 的本机编译，之后比赛实时节点只运行 `.engine`。实时 ROS 订阅、预处理、TensorRT 推理、NMS、JSON 发布都在 C++ `yolo_detector_node` 内完成，绕开 Python/Ultralytics 的运行时开销。

模型文件约定：

```text
源模型：
  /home/nvidia/ros2_ws/src/ylhb_perception/models/yolo26.pt

PC 导出的中间模型：
  /home/nvidia/ros2_ws/src/ylhb_perception/models/yolo26.onnx

开发板最终推理模型：
  /home/nvidia/ros2_ws/src/ylhb_perception/models/yolo26.engine
```

PC 端导出 ONNX：

```bash
pip install -U ultralytics onnx onnxslim
yolo export \
  model=yolo26.pt \
  format=onnx \
  imgsz=960 \
  simplify=True \
  dynamic=False \
  opset=19
```

注意：`imgsz=960` 要和后续 `perception.launch.py` 的 `imgsz:=960` 以及 Jetson 编译出的 `yolo26.engine` 输入尺寸保持一致。当前 C++ 节点启动时会打印 `engine_input=960x960` 作为确认。

导出完成后，把 `yolo26.onnx` 复制到开发板：

```text
/home/nvidia/ros2_ws/src/ylhb_perception/models/yolo26.onnx
```

Jetson 端一次性编译 TensorRT FP16 engine：

```bash
cd ~/ros2_ws
source /opt/ros/humble/setup.bash
source install/setup.bash
ros2 run ylhb_perception export_yolo_trt.py \
  --onnx /home/nvidia/ros2_ws/src/ylhb_perception/models/yolo26.onnx \
  --output /home/nvidia/ros2_ws/src/ylhb_perception/models/yolo26.engine \
  --workspace 2048
```

关键注意：

```text
不要把 .pt 作为比赛实时推理模型。
不要把 PC 上生成的 TensorRT .engine 直接拿到 Jetson 用；engine 和 TensorRT/CUDA/硬件环境强绑定。
如果更换 yolo26.pt 或 imgsz，PC 端重新导出 yolo26.onnx，并在 Jetson 端重新编译 yolo26.engine。
如果用 imgsz=960 导出 ONNX，开发板实时推理也保持 imgsz:=960。
C++ 节点默认拒绝加载 .pt/.onnx 做实时推理；`require_tensorrt:=true` 时必须传入 `.engine`。
```

### 6.3 检查模型类别

如果识别成冰箱、电视、羊，先确认模型类别表：

```bash
python3 - <<'PY'
from ultralytics import YOLO
model = YOLO('/home/nvidia/ros2_ws/src/ylhb_perception/models/yolo26.pt')
print(model.names)
PY
```

如果输出是 COCO 80 类：

```text
person, bicycle, car, ..., sheep, tv, refrigerator
```

说明模型不是比赛目标模型。  
这时识别成冰箱、羊，不是 ROS 问题，是模型类别不匹配。

### 6.4 ZED + YOLO TensorRT 实时识别

终端 1，启动 ZED：

```bash
cd ~/ros2_ws
source install/setup.bash
ros2 launch zed_wrapper zed_camera.launch.py camera_model:=zed2i
```

确认 ZED 图像：

```bash
ros2 topic hz /zed/zed_node/rgb/color/rect/image
ros2 run rqt_image_view rqt_image_view /zed/zed_node/rgb/color/rect/image
```

终端 2，启动 YOLO TensorRT 推理：

> **🧠 核心指令：在线调用 ZED 图像流执行 AI 跟踪**

```bash
cd ~/ros2_ws
source /opt/ros/humble/setup.bash
source install/setup.bash

# 将 ROS2 Launch 入口及参数暴露执行
# 参数全解：
#   model_path:=...       Jetson 本机编译出的 TensorRT .engine 路径
#   backend:=tensorrt     日志标识和安全检查用，C++ 节点实际由 .engine 后缀进入 TensorRT Runtime
#   confidence_threshold:=0.35  偏重识别成功率，先保留较低阈值，再用连续帧稳定确认过滤误检
#   imgsz:=960            提高小目标和远距离物块识别率；必须和编译 engine 的 ONNX 输入尺寸一致
#   max_det:=20           限制最多检测框数量，降低 NMS 后处理开销；静态物块抓取通常足够
#   half:=true            保留 launch 参数兼容；实际 FP16/FP32 由 yolo26.engine 编译方式决定
#   publish_debug_image:=false 比赛运行关闭 ROS2 带框图发布，避免 DDS/Foxglove/rqt 拖慢 FPS
#   show_debug_window:=true     调试时直接弹出本地 OpenCV 窗口看检测效果，不走 ROS2 图像链路
#   debug_window_max_hz:=15.0   本地窗口刷新上限；比赛时 show_debug_window:=false
#   log_interval_sec:=2.0 每 2 秒输出 FPS、推理耗时和识别摘要，便于调试且不刷屏
#   device:=cuda:0        保留 launch 参数兼容；C++ TensorRT 节点直接使用 Jetson CUDA Runtime
ros2 launch ylhb_perception perception.launch.py \
  model_path:=/home/nvidia/ros2_ws/src/ylhb_perception/models/yolo26.engine \
  backend:=tensorrt \
  confidence_threshold:=0.35 \
  imgsz:=960 \
  max_det:=20 \
  half:=true \
  publish_debug_image:=false \
  show_debug_window:=true \
  debug_window_max_hz:=15.0 \
  log_interval_sec:=2.0 \
  device:=cuda:0
```

比赛运行时关闭本地窗口：

```bash
ros2 launch ylhb_perception perception.launch.py \
  model_path:=/home/nvidia/ros2_ws/src/ylhb_perception/models/yolo26.engine \
  backend:=tensorrt \
  confidence_threshold:=0.35 \
  imgsz:=960 \
  max_det:=20 \
  half:=true \
  publish_debug_image:=false \
  show_debug_window:=false \
  log_interval_sec:=2.0 \
  device:=cuda:0
```

查看检测数据：

```bash
ros2 topic echo /perception/detections --once
```

调试时看本地弹出的 `YOLO26 TensorRT Debug` 窗口即可。比赛运行时把 `show_debug_window:=false`。

### 6.5 YOLO 参数怎么调

```text
confidence_threshold
  置信度阈值。
  比赛静态物块推荐 0.35，优先保证识别成功率。
  检测太少：降到 0.25~0.30。
  误检太多：升到 0.45~0.55，并配合连续 3~5 帧稳定确认。

imgsz
  YOLO 输入尺寸。
  640：速度快，适合粗测。
  960：推荐比赛静态物块抓取起点，识别成功率优先。
  1280：小目标更好，但 Jetson 帧率会下降。

max_det
  单帧最多保留多少个检测框。
  比赛静态物块推荐 20，通常足够，且能降低 NMS 后处理耗时。

backend
  C++ 节点中主要用于日志标识和后端一致性检查。
  比赛默认 tensorrt，并且 model_path 必须指向 Jetson 本机编译出的 .engine。
  Python 版 yolo_detector_node.py 仍保留作临时调试/回退，但不是默认 launch 入口。

publish_debug_image
  是否发布 /perception/debug_image ROS2 带框图像。
  比赛运行推荐 false。
  调试识别效果也优先用 show_debug_window，本参数只在需要远程转发或录制 ROS 图像时再打开。
  设为 true 会在 C++ 端画框并通过 DDS 发布图像，可能引入延迟和 Foxglove/rqt 兼容问题。

debug_image_max_hz
  publish_debug_image=true 时的调试图最高发布频率。
  默认 5.0，避免 960x540 大图每帧都走 DDS/Foxglove 把推理主循环拖慢。
  只看识别效果时可用 2~5；录制调试画面时再临时调高。

show_debug_window
  是否弹出本地 OpenCV 调试窗口。
  本机桌面调试推荐 true；比赛运行推荐 false。
  这个窗口不经过 ROS2 topic，不会触发 Foxglove/rqt 的压缩图兼容问题，延迟也更低。

debug_window_max_hz
  本地 OpenCV 窗口最高刷新频率。
  推荐 10~15。设太高会多占 CPU/GPU 显示资源，但不会污染 ROS2 图像话题。

log_interval_sec
  终端状态日志输出间隔。
  推荐 2.0 秒，能看到 FPS、TensorRT 耗时、预处理/后处理耗时，又不会刷屏。

half
  保留给 launch 和旧 Python 节点兼容。
  C++ TensorRT 节点的实际精度由 yolo26.engine 编译结果决定。
  Orin Nano 推荐编译 FP16 engine。

device
  保留给 launch 和旧 Python 节点兼容。
  C++ TensorRT 节点直接使用 Jetson CUDA Runtime，不支持通过该参数切到 CPU。

require_tensorrt
  比赛默认 true。
  true 时如果 model_path 不是 .engine，节点直接拒绝启动，防止误用 .pt/.onnx 跑实时链路。

class_names
  可选类别名列表。
  C++ 节点无法从 .engine 自动恢复训练时的 names 表；为空时 class_name 会输出 class_id 字符串。
  如果上层逻辑依赖类别名，按 class_id 顺序在 detector.yaml 中填写。
```

### 6.6 视觉输出话题

```text
/perception/detections
```

JSON 格式检测结果，包含类别、置信度、检测框。

```text
/perception/debug_image
```

可选 ROS2 带框调试图像。现在本机调试优先用 `show_debug_window:=true` 的 OpenCV 窗口，减少 ROS2 图像链路延迟和兼容问题。

```text
/perception/localized_objects
```

带 3D 粗定位的目标列表。

```text
/perception/target_pose
```

默认发布第一个有效目标的位置。

### 6.7 大模型任务层使用流程

大模型任务层不是替代 YOLO，也不是直接控制底盘和机械臂。它的职责是把比赛任务变成结构化事件：

```text
任务书图片 / 语音 / 文字
  -> retail_task_node
  -> 图片理解、意图解析、商品推荐、购物车、结算播报
  -> /retail_ai/task_event
  -> 导航/抓取层执行
  -> /retail_ai/task_status
  -> retail_task_node 根据执行结果更新购物车并播报
```

#### 6.7.1 编译新增接口和大模型包

新增了 `ylhb_interfaces` 和 `ylhb_llm` 两个包，第一次使用前需要重新编译：

```bash
cd ~/ros2_ws
source /opt/ros/humble/setup.bash
colcon build --packages-select ylhb_interfaces ylhb_llm --symlink-install
source install/setup.bash
```

如果构建时报 Python `setuptools` / `packaging` 相关错误，通常是用户目录里的 Python 包版本和 ROS 2 Humble 不兼容。可以临时隔离用户 Python 包构建：

```bash
cd ~/ros2_ws
PYTHONNOUSERSITE=1 bash -lc \
  'source /opt/ros/humble/setup.bash && colcon build --packages-select ylhb_interfaces ylhb_llm --symlink-install'
source install/setup.bash
```

确认接口存在：

```bash
ros2 interface show ylhb_interfaces/msg/TaskEvent
```

#### 6.7.2 设置 DashScope Key

大模型调用使用 DashScope 云 API，Key 只放在环境变量里，不写进代码和 YAML：

```bash
export DASHSCOPE_API_KEY=你的DashScope_API_Key
```

如果没有设置 Key，文字指令中的本地规则仍可识别简单商品名，但任务书图片理解、云端 ASR、云端 TTS 会失败并输出明确原因。

默认模型参数在 `src/ylhb_llm/config/llm.yaml`：

```text
vl_model: qwen3.7-plus
chat_model: qwen3.7-plus
asr_model: qwen3-asr-flash
tts_model: qwen3-tts-flash
dashscope_base_url: https://dashscope.aliyuncs.com/compatible-mode/v1
vision_timeout_sec: 45.0
request_timeout_sec: 12.0
```

视觉和文字结构化解析统一使用 `qwen3.7-plus` 多模态大模型。视觉请求必须支持 `image_url`；请求会显式使用 `enable_thinking=false`，避免思考模式拖慢响应，适合比赛现场 60 秒响应限制。

如果实际 DashScope 控制台里的模型 ID 不同，启动时直接覆盖：

```bash
ros2 launch ylhb_llm llm.launch.py \
  vl_model:=qwen3.7-plus \
  chat_model:=qwen3.7-plus \
  enable_voice:=false \
  enable_tts:=false
```

#### 6.7.2.1 `llm.yaml` 参数全解

配置文件位置：

```text
/home/nvidia/ros2_ws/src/ylhb_llm/config/llm.yaml
```

`retail_task_node` 参数：

| 参数 | 默认值 | 说明 | 调试建议 |
|---|---|---|---|
| `products_file` | `.../products.yaml` | 商品库路径，维护商品 ID、名称、别名、价格、推荐权重 | 现场商品名称或价格变化时优先改这里 |
| `text_command_topic` | `/retail_ai/text_command` | 文字任务输入话题，也接收 ASR 后文字 | 一般不改 |
| `localized_objects_topic` | `/perception/localized_objects` | VLM 保分模式或 YOLO+深度定位增强模式后的商品结果 | 必须和识别节点输出一致 |
| `task_event_topic` | `/retail_ai/task_event` | AI 层发给导航/抓取层的任务事件 | 导航/抓取层订阅这个 |
| `task_status_topic` | `/retail_ai/task_status` | 导航/抓取层回传执行状态 | 成功后才会加入购物车 |
| `say_text_topic` | `/retail_ai/say_text` | 所有播报文本输出 | 可用 `ros2 topic echo` 调试 |
| `cart_topic` | `/retail_ai/cart` | 购物车状态和总价 | 用于结算调试 |
| `start_b1_service_name` | `/retail_ai/start_b1_task` | B-1 标准 Trigger 启动 service | 一般不改 |
| `task_image_dir` | `/home/nvidia/ros2_ws/src/ylhb_llm/test_images` | B-1 任务书图片目录 | 比赛时只保留一张 jpg/jpeg/png |
| `system_mode_topic` | `/retail_ai/system_mode` | 显示屏全局模式控制 | sleep/fault 下不启动普通任务 |
| `shelf_snapshot_ttl_sec` | `2.0` | 货架识别结果有效期，超过则不推荐 | 货架识别频率低时可调到 3~5 |
| `dashscope_base_url` | `https://dashscope.aliyuncs.com/compatible-mode/v1` | DashScope 北京地域 OpenAI 兼容地址 | 国际地域改 `dashscope-intl` |
| `vl_model` | `qwen3.7-plus` | 图片理解模型 | 必须支持 `image_url` |
| `chat_model` | `qwen3.7-plus` | 文字意图解析模型 | 与视觉统一使用 qwen3.7-plus |
| `request_timeout_sec` | `12.0` | 普通文本请求超时 | 文字解析慢时调大；比赛不建议超过 20 |
| `vision_timeout_sec` | `45.0` | 图片理解请求超时 | 仍超时时可临时调到 60 |
| `publish_raw_json` | `true` | 是否保留调试 JSON | 比赛稳定后可设 false 减少消息长度 |
| `voice_requires_confirmation` | `true` | 连续语音 B-2 是否需要确认后取货 | 比赛建议保持 true |

`basic_motion_command_node` 参数：

| 参数 | 默认值 | 说明 | 调试建议 |
|---|---|---|---|
| `text_command_topic` | `/retail_ai/text_command` | A-1 基本运动文字/ASR 输入 | 和 voice_input_node 保持一致 |
| `cmd_vel_topic` | `/cmd_vel` | 底盘速度控制话题 | 一般不改 |
| `linear_speed` | `0.12` | 前进/后退速度，单位 m/s | 首次调试低速 |
| `angular_speed` | `0.45` | 左转/右转角速度，单位 rad/s | 现场按底盘响应微调 |
| `motion_duration_sec` | `1.0` | 单条运动指令持续时间 | 到时自动发布零速度 |

`voice_input_node` 参数：

| 参数 | 默认值 | 说明 | 调试建议 |
|---|---|---|---|
| `text_command_topic` | `/retail_ai/text_command` | ASR 后文字发布到这里 | 和 retail_task_node 保持一致 |
| `capture_voice_service_name` | `/retail_ai/capture_voice` | 按钮触发录音识别服务 | UI 语音输入按钮调用这个服务 |
| `audio_input_device` | `default` | ALSA 录音设备 | eMeet Luna 推荐 `plughw:CARD=Luna,DEV=0` |
| `audio_device` | `default` | 旧版兼容参数 | 旧命令仍可传 `audio_device:=hw:2,0` |
| `record_sec` | `4.0` | 每次录音秒数 | 短命令 3~5 秒，太长会增加延迟 |
| `sample_rate` | `16000` | 录音采样率 | 中文短语音 16000 足够 |
| `enabled` | `false` | 是否启用语音输入 | 没接 eMeet Luna 时保持 false |
| `dashscope_base_url` | `https://dashscope.aliyuncs.com/compatible-mode/v1` | ASR 调用地址 | 和主节点保持一致 |
| `asr_model` | `qwen3-asr-flash` | ASR 模型 ID | 按百炼控制台可用模型调整 |
| `request_timeout_sec` | `15.0` | ASR 请求超时 | 现场短语音建议 10~15 |

`voice_output_node` 参数：

| 参数 | 默认值 | 说明 | 调试建议 |
|---|---|---|---|
| `say_text_topic` | `/retail_ai/say_text` | 播报请求输入话题 | 和 retail_task_node 保持一致 |
| `voice_status_topic` | `/retail_ai/voice_status` | 当前播报状态输出 | 用于确认是否正在说话 |
| `enabled` | `false` | 是否启用播放功能 | 先 false，只看 SAY 日志 |
| `tts_enabled` | `false` | 是否调用云端 TTS | 要真正出声需和 `enabled` 都为 true |
| `audio_output_device` | `default` | ALSA 播放设备 | eMeet Luna 推荐 `plughw:CARD=Luna,DEV=0` |
| `audio_device` | `default` | 旧版兼容参数 | 旧命令仍可用 |
| `dashscope_base_url` | `https://dashscope.aliyuncs.com/compatible-mode/v1` | TTS 调用地址 | 和主节点保持一致 |
| `tts_model` | `qwen3-tts-flash` | TTS 模型 ID | 按百炼控制台可用模型调整 |
| `tts_voice` | `Serena` | TTS 女声音色 | 默认使用更柔和的中文女声，可按百炼控制台支持音色调整 |
| `tts_language_type` | `Chinese` | TTS 语言 | 中文播报固定 Chinese |
| `request_timeout_sec` | `10.0` | TTS 请求超时 | 播报内容长时可调大 |

`voice_session_node` 参数：

| 参数 | 默认值 | 说明 | 调试建议 |
|---|---|---|---|
| `voice_command_event_topic` | `/retail_ai/voice_command_event` | 连续语音识别事件输出 | 一般不改 |
| `voice_session_status_topic` | `/retail_ai/voice_session_status` | 连续语音状态输出 | UI 订阅显示 |
| `start_voice_session_service_name` | `/retail_ai/start_voice_session` | 开启连续语音服务 | UI A-2 按钮调用 |
| `stop_voice_session_service_name` | `/retail_ai/stop_voice_session` | 关闭连续语音服务 | UI A-2 按钮调用 |
| `audio_input_device` | `default` | ALSA 录音设备 | competition 覆盖为 `plughw:CARD=Luna,DEV=0` |
| `enabled` | `false` | 节点启动后是否立即启用连续语音 | competition 覆盖为 true |
| `asr_model` | `qwen3-asr-flash` | ASR 模型 ID | 按百炼控制台可用模型调整 |
| `request_timeout_sec` | `15.0` | ASR 请求超时 | 现场短语音建议 10~15 |
| `wake_phrase` | `小零小零` | 唤醒词 | 同时支持常见 ASR 近音别名 |
| `session_idle_timeout_sec` | `35.0` | 唤醒后无操作回到待唤醒的时间 | 现场噪声大可适当调小 |
| `max_utterance_sec` | `6.0` | 单句最长录音时间 | 长句被截断时再调大 |
| `post_event_listen_pause_sec` | `3.0` | 发布语音事件后暂停监听，避免吃进 TTS | 播报串入 ASR 时调大 |

`system_supervisor_node` 参数：

| 参数 | 默认值 | 说明 |
|---|---|---|
| `map_output_dir` | `/home/nvidia/ros2_ws/src/maps` | `save_map` 保存目录 |
| `default_navigation_map` | `/home/nvidia/ros2_ws/maps/my_map.yaml` | `start_navigation` 默认比赛地图 |
| `perception_model_path` | `/home/nvidia/ros2_ws/src/ylhb_perception/models/yolo26.engine` | supervisor 启动感知时使用的 TensorRT engine |
| `embedded_task_layer` | `true` | competition 模式下 AI 任务层已内嵌，不重复启动 |

常用启动覆盖示例：

```bash
# 图片理解仍超时，先改 src/ylhb_llm/config/llm.yaml 里的 vision_timeout_sec，再启动
ros2 launch ylhb_llm llm.launch.py enable_voice:=false enable_tts:=false

# 接入 eMeet Luna，开启连续语音会话，不播放
ros2 launch ylhb_llm llm.launch.py \
  enable_voice:=true \
  enable_voice_session:=true \
  enable_tts:=false \
  audio_input_device:=plughw:CARD=Luna,DEV=0

# 最高效果但开启真实播报
ros2 launch ylhb_llm llm.launch.py \
  vl_model:=qwen3.7-plus \
  chat_model:=qwen3.7-plus \
  enable_voice:=true \
  enable_tts:=true \
  audio_input_device:=plughw:CARD=Luna,DEV=0 \
  audio_output_device:=plughw:CARD=Luna,DEV=0
```

#### 6.7.3 启动大模型任务层

推荐先关闭语音输入和 TTS，只验证文字、图片 service、结构化事件和播报文本：

```bash
cd ~/ros2_ws
source /opt/ros/humble/setup.bash
source install/setup.bash
export DASHSCOPE_API_KEY=你的DashScope_API_Key
ros2 launch ylhb_llm llm.launch.py enable_voice:=false enable_tts:=false
```

也可以用统一脚本：

```bash
cd ~/ros2_ws
export DASHSCOPE_API_KEY=你的DashScope_API_Key
./scripts/run_on_jetson.sh llm enable_voice:=false enable_tts:=false
```

启动后应看到：

```text
retail_task_node started with 16 products
Basic motion command node started.
Voice input started: enabled=False
Voice output started: enabled=False, tts_enabled=False
```

此时 `/retail_ai/say_text` 会发布结构化播报消息，`voice_output_node` 会在终端打印 `SAY[...]`，但不会播放声音。

#### 6.7.4 任务 A-1 基本运动

键盘控制直接使用 `teleop_twist_keyboard`：

```bash
ros2 run teleop_twist_keyboard teleop_twist_keyboard
```

语音或文字控制最终走统一文字入口。连续语音模式下，ASR 结果会先进入 `/retail_ai/voice_command_event`，再由 `voice_command_router_node` 按安全指令、A-2 运动、B-2 销售、C 结算分流后发布到 `/retail_ai/text_command`：

```bash
ros2 topic pub --once /retail_ai/text_command std_msgs/msg/String "{data: '前进'}"
ros2 topic pub --once /retail_ai/text_command std_msgs/msg/String "{data: '后退'}"
ros2 topic pub --once /retail_ai/text_command std_msgs/msg/String "{data: '左转'}"
ros2 topic pub --once /retail_ai/text_command std_msgs/msg/String "{data: '右转'}"
ros2 topic pub --once /retail_ai/text_command std_msgs/msg/String "{data: '停止'}"
```

`basic_motion_command_node` 会发布短时 `/cmd_vel`，到时自动发布零速度。A-1 规则只要求机器人按键盘和语音完成基本运动，不要求每个动作都有固定 AI 播报，所以这里不把“好的，机器人开始前进”写成强制流程。

#### 6.7.5 任务 A-2：唤醒式连续语音交互

UI 的 A-2 区块提供“开启语音模式 / 关闭语音模式”。开启后机器人会本地监听 eMeet Luna 麦克风，静音时不调用 ASR；检测到人声后自动分段录音并送 DashScope ASR。未唤醒时只接受“小零小零”等唤醒词，支持“小玲小玲 / 小灵小灵 / 小林小林 / 小零 / 小玲”等 ASR 常见变体。

连续语音链路：

```text
eMeet Luna 麦克风 -> voice_session_node VAD -> DashScope ASR
-> /retail_ai/voice_command_event(JSON)
-> voice_command_router_node
-> /retail_ai/text_command(JSON 或兼容纯文本)
-> A-1 / B-2 / C 对应任务节点
```

调试命令：

```bash
ros2 service call /retail_ai/start_voice_session std_srvs/srv/Trigger "{}"
ros2 topic echo /retail_ai/voice_session_status
ros2 topic echo /retail_ai/voice_command_event
ros2 service call /retail_ai/stop_voice_session std_srvs/srv/Trigger "{}"
```

说“小零小零，我口渴了”时，系统会去掉唤醒词，把“我口渴了”作为同一句指令继续进入 B-2 销售对话。未唤醒时说“确认”会被忽略，不会触发取货。

#### 6.7.6 任务 B-1：导入图片、到货架后推荐

任务 B 中“选手导入任务书提供的待识别图片”用 service 完成：

```bash
ros2 service call /retail_ai/start_b1_task std_srvs/srv/Trigger "{}"
```

项目内已经预留本地测试图片目录：

```text
/home/nvidia/ros2_ws/src/ylhb_llm/test_images/
```

把任务书图片复制到这个目录，例如：

```text
/home/nvidia/ros2_ws/src/ylhb_llm/test_images/task_b.png
```

目录内只保留这一张 `.jpg/.jpeg/.png` 图片，然后测试 B-1 启动：

```bash
ros2 service call /retail_ai/start_b1_task std_srvs/srv/Trigger "{}"
```

返回字段含义：

```text
success       true 表示 B-1 任务入口已启动
message       JSON 字符串，包含 task_id、stage、image_path、say_text、error
```

图片分析不是直接让大模型决定最终商品。实际推荐流程是：

```text
1. Qwen-VL 理解图片：例如“男孩口渴，需要喝水”
2. retail_task_node 先播报图片理解内容
3. 发布 /retail_ai/task_event：intent=inspect_shelf_for_recommendation, destination=shelf
4. 导航/抓取层让机器人从起点 S 去货架区 A，并启动/等待货架识别
5. 执行层回传 status=succeeded, stage=inspect_shelf
6. retail_task_node 读取 /perception/localized_objects 中当前货架真实商品
7. 本地商品库 products.yaml 做别名、类别、推荐权重匹配
8. 从货架真实存在且未过期的商品里选最终商品并播报
9. 发布第二个 /retail_ai/task_event：intent=pick_item, destination=checkout
```

重要限制：

```text
推荐商品必须来自货架区 A 当前陈列且识别到的商品。
/perception/localized_objects 超过 2 秒没有更新，货架快照视为过期。
货架快照过期时不会硬推荐商品，会播报“请重新对准货架”。
这样可以避免拿到上一轮货架识别结果。
```

手动模拟 B-1 后半段：

```bash
# 1. 导入任务书图片后，查看第一个 task_event 的 task_id
ros2 topic echo /retail_ai/task_event --once

# 2. 让感知节点持续发布当前货架商品，或手动发布一帧 localized_objects
# 3. 模拟执行层已经到达货架并完成识别
ros2 topic pub --once /retail_ai/task_status ylhb_interfaces/msg/TaskStatus \
  "{task_id: '替换成实际task_id', stage: 'inspect_shelf', status: 'succeeded', reason: ''}"
```

此时应看到推荐商品播报，并出现第二个 `pick_item` 任务事件。

#### 6.7.7 任务 B-2：文字或语音购物

文字输入是比赛现场最可靠的兜底方式。B-2 现在采用销售式对话：文本明确商品名可直接执行；连续语音模式下即使用户说“来瓶可乐”，也会先形成待确认推荐，必须再说“确认 / 确定 / 就这个 / 开始取货 / 帮我拿这个”才执行取货。

```bash
ros2 topic pub --once /retail_ai/text_command std_msgs/msg/String "{data: '来瓶可乐'}"
ros2 topic pub --once /retail_ai/text_command std_msgs/msg/String "{data: '我口渴了'}"
ros2 topic pub --once /retail_ai/text_command std_msgs/msg/String "{data: '确认'}"
```

需求型表达先查看销售对话状态：

```bash
ros2 topic echo /retail_ai/sales_dialogue_status --once
```

连续语音 B-2 典型流程：

```text
用户：小零小零，我口渴了
机器人：主推矿泉水，并给出备选，等待确认
用户：换一个 / 不要碳酸的 / 便宜点
机器人：更新推荐
用户：确认
机器人：好的，为您提取对应商品，并发布 B-2 pick_item
```

典型内容：

```json
{
  "active": true,
  "state": "awaiting_confirmation",
  "primary_product_name": "农夫山泉矿泉水",
  "primary_price": 2.0,
  "related_products": [
    {"product_name": "纯牛奶", "price": 3.0},
    {"product_name": "可口可乐", "price": 3.0}
  ],
  "last_reply": "您可能需要解渴，我主推农夫山泉矿泉水..."
}
```

对于待确认销售对话，用户确认后查看 AI 层输出的任务事件；纯文字明确商品名的兜底输入可能直接发布该事件：

```bash
ros2 topic echo /retail_ai/task_event --once
```

典型内容：

```text
task_id: text_...
intent: pick_item
item_id: cola_coca 或 cola_pepsi
item_name: 可口可乐 或 百事可乐
destination: checkout
source: voice 或 text
requires_ack: true
```

收到购物指令后，规则明确要求机器人语音播报相应信息。`retail_task_node` 会发布类似“您可能需要解渴，我主推农夫山泉矿泉水...”或“好的，为您提取可口可乐。”的播报文本。

导航/抓取层收到 `/retail_ai/task_event` 后，应开始导航到货架区 A，识别货架当前陈列商品，找到目标商品，抓取，导航到结算区 B，放置商品，然后返回起点 S。每个阶段完成后，通过 `/retail_ai/task_status` 回传状态。

#### 6.7.8 执行状态回传和购物车更新

AI 层不会在发布 `pick_item` 后立刻把商品加入购物车。只有执行层回传成功，才认为商品已放入结算区。

手动模拟抓取成功：

```bash
ros2 topic pub --once /retail_ai/task_status ylhb_interfaces/msg/TaskStatus \
  "{task_id: 'text_替换成实际ID', stage: 'place', status: 'succeeded', reason: ''}"
```

手动模拟失败：

```bash
ros2 topic pub --once /retail_ai/task_status ylhb_interfaces/msg/TaskStatus \
  "{task_id: 'text_替换成实际ID', stage: 'grasp', status: 'failed', reason: '商品不在可抓取范围内'}"
```

规则：

```text
status=started                              AI 层播报“已开始执行任务”
pick_item + stage=place + status=succeeded  对应商品加入购物车，并播报已放入结算区
inspect_shelf + status=succeeded            B-1 进入货架真实商品推荐
checkout_inspect + status=succeeded         C 任务播报结算区商品清单并发布回起点事件
return_start + status=succeeded             C 任务按价格表播报总价
status=failed                               播报失败原因，不更新购物车
status=rejected                             播报拒绝原因，不更新购物车
```

同一个 `task_id` 只会入账一次，防止重复执行状态导致购物车重复计数。

#### 6.7.9 任务 C：结算指令

输入结算指令：

```bash
ros2 topic pub --once /retail_ai/text_command std_msgs/msg/String "{data: '一共多少钱'}"
```

AI 层不会直接读取旧购物车完成结算。正确流程是发布结算任务事件，让执行层导航到结算区 B，识别结算区内所有商品：

```text
intent: checkout
destination: checkout
source: checkout
```

执行层完成结算区识别后回传：

```bash
ros2 topic pub --once /retail_ai/task_status ylhb_interfaces/msg/TaskStatus \
  "{task_id: '替换成实际task_id', stage: 'checkout_inspect', status: 'succeeded', reason: ''}"
```

`retail_task_node` 会根据最近一帧 `/perception/localized_objects` 统计商品名称和数量，播报商品清单：

```text
您选购的商品有：1件农夫山泉矿泉水、1件可口可乐。
```

随后发布 `intent=return_start, destination=start`。执行层回到起点 S 后回传：

```bash
ros2 topic pub --once /retail_ai/task_status ylhb_interfaces/msg/TaskStatus \
  "{task_id: '替换成实际task_id', stage: 'return_start', status: 'succeeded', reason: ''}"
```

最后 AI 层按 `products.yaml` 价格表计算并播报总价：

```text
您购买的商品总价为5元。
```

查看结算统计：

```bash
ros2 topic echo /retail_ai/cart --once
```

注意：最终金额不由大模型计算，避免大模型在加法上出现幻觉。现场价格变化时只改 `products.yaml`。

#### 6.7.10 eMeet Luna 语音输入和 TTS 播放

当前机器使用 eMeet Luna 一体式音箱/麦克风。插上 USB 后先确认：

```bash
lsusb | grep -i emeet
arecord -l
aplay -l
```

本机已验证 USB 枚举为：

```text
328f:2001 eMeet eMeet Luna
```

`arecord -l` 和 `aplay -l` 应能看到类似：

```text
card 2: Luna [eMeet Luna], device 0: USB Audio [USB Audio]
```

推荐使用 `plughw:CARD=Luna,DEV=0`，比 `hw:2,0` 更不依赖 card 编号。调试单次录音 ASR 时开启 `enable_capture_voice`，不开 TTS：

```bash
ros2 launch ylhb_llm llm.launch.py \
  enable_voice:=false \
  enable_capture_voice:=true \
  enable_tts:=false \
  audio_input_device:=plughw:CARD=Luna,DEV=0
```

语音输入分两种入口：比赛交互使用 A-2 的唤醒式连续语音模式；`/retail_ai/capture_voice` 保留为单次 ASR 调试接口。命令行触发一次录音识别：

```bash
ros2 service call /retail_ai/capture_voice std_srvs/srv/Trigger "{}"
```

单次调试链路：

```text
eMeet Luna 麦克风 -> /retail_ai/capture_voice -> voice_input_node -> 云端 ASR
-> /retail_ai/text_command -> retail_task_node
```

连续语音链路会多一层结构化事件和路由：

```text
eMeet Luna 麦克风 -> voice_session_node -> /retail_ai/voice_command_event
-> voice_command_router_node -> /retail_ai/text_command -> retail_task_node/basic_motion_command_node
```

开启 TTS 播放：

```bash
ros2 launch ylhb_llm llm.launch.py \
  enable_voice:=true \
  enable_voice_session:=true \
  enable_tts:=true \
  audio_input_device:=plughw:CARD=Luna,DEV=0 \
  audio_output_device:=plughw:CARD=Luna,DEV=0 \
  tts_voice:=Serena
```

播报链路：

```text
retail_task_node -> /retail_ai/say_text -> voice_output_node -> 云端 TTS
-> 下载 wav -> aplay -> eMeet Luna 扬声器
```

`voice_output_node` 内部有播报队列，`SayText.priority` 越大越优先，`interrupt=true` 会清空等待队列。这样图像理解、推荐商品、结算播报不会重叠播放。

当前 ASR 使用 DashScope 同步 multimodal 接口的最小请求体：`input.messages` 内只放一条 `user` 消息，消息内容只包含 `audio: data:audio/wav;base64,...`。连续语音模式会给每句话生成 `session_id` 和 `utterance_id`，B-2 确认取货时再生成 `task_request_id`，用于避免重复执行同一条确认。

#### 6.7.11 商品库和推荐规则

商品库位置：

```text
/home/nvidia/ros2_ws/src/ylhb_llm/config/products.yaml
```

每个商品必须有标准 ID，不只写中文名：

```yaml
- id: water_nongfu
  name: 农夫山泉矿泉水
  category: water
  price: 2.0
  aliases: [农夫山泉矿泉水, 农夫山泉, 矿泉水, 水, 饮用水]
  priority_for_intents: {thirsty: 100, drink: 95}
```

推荐时优先使用：

```text
商品是否在当前货架识别结果中
商品别名是否匹配用户文字
大模型输出的 need 和 preferred_categories
products.yaml 中 priority_for_intents 的本地权重
```

如果比赛现场商品清单、价格或名称有变化，优先改 `products.yaml`，不要改代码。

---

## 7. 关键话题解释

### 7.1 `/cmd_vel`

类型：`geometry_msgs/msg/Twist`  
发布：Nav2、键盘遥控、上层任务逻辑  
订阅：当前底盘后端，默认 `zlac8015d_canopen_controller`；回退时为 `base_controller`  
作用：控制底盘线速度和角速度。

### 7.2 `/odom`

类型：`nav_msgs/msg/Odometry`  
发布：当前底盘后端，默认 `zlac8015d_canopen_controller`；回退时为 `base_controller`  
订阅：`ekf_filter_node`  
作用：底盘编码器计算出的轮式里程计。

### 7.3 `/imu/data`

类型：`sensor_msgs/msg/Imu`  
发布：`imu_driver`  
订阅：`ekf_filter_node`  
作用：IMU 姿态、角速度、线加速度。

### 7.4 `/scan`

类型：`sensor_msgs/msg/LaserScan`  
发布：`rplidar_node`  
订阅：`slam_toolbox`、Nav2、AMCL  
作用：建图、定位、避障。

### 7.5 `/zed/zed_node/rgb/color/rect/image`

类型：`sensor_msgs/msg/Image`  
发布：`zed_wrapper`  
订阅：`yolo_detector_node`  
作用：YOLO26 的实时图像输入。

注意：

```text
ros2 topic echo 这个话题时看到 data=Uint8Array(...) 是正常的原始像素数组。
看图像要用 rqt_image_view。
```

### 7.6 `/perception/detections`

类型：`std_msgs/msg/String`，内容是 JSON  
发布：`yolo_detector_node`  
订阅：`object_localizer_node.py`、上层任务逻辑  
作用：AI 检测结果。

### 7.7 `/perception/debug_image`

类型：`sensor_msgs/msg/Image`  
发布：`yolo_detector_node`  
订阅：调试工具  
作用：可选带框可视化图像。默认调试建议使用本地 OpenCV 窗口；只有需要远程转发、录制 ROS topic 或给其它节点消费时才打开这个 topic。

### 7.8 `/retail_ai/start_b1_task`

类型：`std_srvs/srv/Trigger`  
服务端：`retail_task_node`  
客户端：显示屏 UI、选手命令行、比赛上层控制脚本  
作用：启动 B-1 图片推荐任务。请求为空，任务层从 `task_image_dir` 读取唯一任务书图片，返回 JSON message。

调用示例：

```bash
ros2 service call /retail_ai/start_b1_task std_srvs/srv/Trigger "{}"
```

### 7.9 `/retail_ai/text_command`

类型：`std_msgs/msg/String`  
发布：命令行、`voice_input_node`、比赛上层输入界面  
订阅：`retail_task_node`、`basic_motion_command_node`  
作用：文字任务入口，也承接 ASR 后的语音转写结果；A-1 基本运动指令也走这里。

典型输入：

```text
来瓶可乐
拿一瓶矿泉水
一共多少钱
前进
左转
```

### 7.10 `/retail_ai/sales_dialogue_status`

类型：`std_msgs/msg/String`，内容为 JSON
发布：`retail_task_node`
订阅：比赛 UI、`voice_command_router_node`
作用：显示 B-2 销售对话的当前状态、主推商品、相关备选商品和机器人最近回复。UI 只展示该状态，不负责商品决策。连续语音 B-2 必须在这里进入 `awaiting_confirmation` 后，由用户确认才会执行取货。

关键字段：

```text
active
state                 # idle / awaiting_confirmation / asking_clarification
primary_product_id
primary_product_name
primary_price
related_products
pending_product_id
pending_product_name
waiting_for
last_reply
```

### 7.11 `/retail_ai/voice_command_event`

类型：`std_msgs/msg/String`，内容为 JSON
发布：`voice_session_node`
订阅：`voice_command_router_node`
作用：连续语音 ASR 后的结构化事件。字段包括 `source/session_id/utterance_id/text/raw_asr_text/awakened/contains_wake_phrase/confidence/timestamp`。

### 7.12 `/retail_ai/voice_session_status`

类型：`std_msgs/msg/String`，内容为 JSON
发布：`voice_session_node`
订阅：比赛 UI、调试工具
作用：连续语音会话状态。字段包括 `enabled/state/wake_phrase/awakened/session_id/waiting_for/is_tts_playing/is_recording/asr_fail_count/last_asr_text/last_published_text/last_error/last_update_time`。

### 7.13 语音服务

```text
/retail_ai/capture_voice
/retail_ai/start_voice_session
/retail_ai/stop_voice_session
```

类型均为：`std_srvs/srv/Trigger`。`capture_voice` 是按键式单次录音 ASR；`start_voice_session` 和 `stop_voice_session` 控制唤醒式连续语音会话。

### 7.14 `/retail_ai/task_event`

类型：`ylhb_interfaces/msg/TaskEvent`  
发布：`retail_task_node`  
订阅：导航/抓取层、比赛上层控制脚本  
作用：把大模型和本地规则解析后的意图变成结构化任务。

执行层重点读取：

```text
task_id
intent         # inspect_shelf_for_recommendation / pick_item / checkout / return_start
item_id        # pick_item 时有商品 ID；流程事件可为空
item_name      # pick_item 时有商品名；流程事件可为空
destination    # shelf / checkout / start
confidence
source
requires_ack
raw_json
```

### 7.15 `/retail_ai/task_status`

类型：`ylhb_interfaces/msg/TaskStatus`  
发布：导航/抓取层、比赛上层控制脚本  
订阅：`retail_task_node`  
作用：告诉 AI 层任务是否开始、成功、失败或被拒绝。

关键 `stage/status` 约定：

```text
inspect_shelf + succeeded       B-1 到达货架 A 且完成货架识别，AI 层再推荐真实货架商品
place + succeeded               B-1/B-2 商品已放入结算区，AI 层更新购物车
checkout_inspect + succeeded    C 到达结算区 B 且完成商品识别，AI 层播报商品清单
return_start + succeeded        C 已回到起点 S，AI 层播报结算总价
failed/rejected                 AI 层播报 reason，不更新购物车
```

### 7.16 `/retail_ai/say_text`

类型：`ylhb_interfaces/msg/SayText`  
发布：`retail_task_node`  
订阅：`voice_output_node`  
作用：统一播报队列入口，支持优先级和打断。

调试时即使不开 TTS，也可以 echo 这个话题确认机器人应该说什么。

### 7.17 `/retail_ai/voice_status`

类型：`ylhb_interfaces/msg/VoiceStatus`  
发布：`voice_output_node`  
订阅：调试工具、上层控制脚本  
作用：查看当前是否正在播报，以及正在播报哪个任务。

### 7.18 `/retail_ai/cart`

类型：`ylhb_interfaces/msg/CartState`  
发布：`retail_task_node`  
订阅：调试工具、结算展示脚本  
作用：当前购物车和总价。总价由本地代码按 `products.yaml` 计算。

字段：

```text
header
schema_version
items      # RecognizedProduct[]
total
raw_json
```

---

## 8. 常用调试命令

查看包：

```bash
ros2 pkg list | grep -E 'ylhb|zed|rplidar'
```

确认新增接口：

```bash
ros2 interface show ylhb_interfaces/msg/TaskEvent
ros2 interface show ylhb_interfaces/msg/CartState
```

查看话题：

```bash
ros2 topic list
```

查看图像：

```bash
ros2 run rqt_image_view rqt_image_view /zed/zed_node/rgb/color/rect/image
```

查看 YOLO 检测效果推荐本地窗口：

```bash
ros2 launch ylhb_perception perception.launch.py \
  model_path:=/home/nvidia/ros2_ws/src/ylhb_perception/models/yolo26.engine \
  publish_debug_image:=false \
  show_debug_window:=true \
  debug_window_max_hz:=15.0
```

注意不要在 Foxglove/rqt 中订阅 `/zed/zed_node/depth/depth_registered/compressed`。深度图是 `32FC1` 浮点图，JPEG compressed 不支持，会导致 ZED 终端持续刷 `CompressedPublisher` 错误。需要看深度时用原始 `/zed/zed_node/depth/depth_registered` 或 `/compressedDepth`。

查看话题频率：

```bash
ros2 topic hz /zed/zed_node/rgb/color/rect/image
ros2 topic hz /perception/detections
ros2 topic hz /scan
```

查看检测结果：

```bash
ros2 topic echo /perception/detections --once
ros2 topic echo /perception/localized_objects --once
ros2 topic echo /perception/target_pose --once
```

启动大模型任务层：

```bash
export DASHSCOPE_API_KEY=你的DashScope_API_Key
ros2 launch ylhb_llm llm.launch.py enable_voice:=false enable_tts:=false
```

调用任务书图片分析：

```bash
ros2 service call /retail_ai/start_b1_task std_srvs/srv/Trigger "{}"
```

发送文字购物指令：

```bash
ros2 topic pub --once /retail_ai/text_command std_msgs/msg/String "{data: '来瓶可乐'}"
```

查看大模型任务层输出：

```bash
ros2 topic echo /retail_ai/task_event --once
ros2 topic echo /retail_ai/say_text --once
ros2 topic echo /retail_ai/cart --once
ros2 topic echo /retail_ai/voice_status --once
```

模拟执行层成功回传：

```bash
ros2 topic pub --once /retail_ai/task_status ylhb_interfaces/msg/TaskStatus \
  "{task_id: '替换成实际task_id', stage: 'place', status: 'succeeded', reason: ''}"
```

检查 eMeet Luna 声卡：

```bash
arecord -l
aplay -l
```

查看底盘：

```bash
ros2 topic echo /odom --once
ros2 topic echo /imu/data --once
ros2 topic echo /scan --once
```

查看 TF：

```bash
ros2 run tf2_tools view_frames
```

---

## 9. 比赛前检查清单

### 9.1 建图前

```text
雷达 /scan 正常
IMU /imu/data 正常
底盘 /odom 正常
TF 中 base_footprint -> laser_link 正常
小车低速运动稳定
```

### 9.2 导航前

```text
my_map.yaml 和 my_map.pgm 存在
/map 正常发布
默认原点启动或已发布 /initialpose 覆盖，且 /scan 与 /map 基本贴合
AMCL 能定位
map -> odom -> base_footprint TF 连通
Nav2 能发布 /cmd_vel
底盘能响应 /cmd_vel
```

### 9.3 AI 识别前

```text
ZED RGB 图像正常显示
YOLO 模型类别表正确
/home/nvidia/ros2_ws/src/ylhb_perception/models/yolo26.engine 存在
C++ yolo_detector_node 能启动并打印 backend=tensorrt
调试模式下本地 OpenCV 窗口有带框图
/perception/detections 有检测 JSON
如果需要深度定位，/perception/target_pose 有输出
```

### 9.4 大模型任务层前

```text
ylhb_interfaces 和 ylhb_llm 已重新 colcon build
source /opt/ros/humble/setup.bash 和 source install/setup.bash 已执行
DASHSCOPE_API_KEY 已设置
ros2 launch ylhb_llm llm.launch.py enable_voice:=false enable_tts:=false 能启动
/retail_ai/start_b1_task service 存在
/retail_ai/text_command 输入“来瓶可乐”后 /retail_ai/task_event 有输出
/retail_ai/say_text 能看到机器人应播报文本
products.yaml 中 16 类商品价格和现场任务书一致
如果使用语音，arecord -l 和 aplay -l 能看到 eMeet Luna 或可用声卡
```

---

## 10. 常见问题

### 10.1 YOLO 把目标识别成冰箱、电视、羊

原因通常是当前模型是 COCO 80 类模型，不是比赛目标模型。

检查：

```bash
python3 - <<'PY'
from ultralytics import YOLO
model = YOLO('/home/nvidia/ros2_ws/src/ylhb_perception/models/yolo26.pt')
print(model.names)
PY
```

解决：

```text
换成真正训练过比赛目标的 YOLO26 模型。
```

### 10.2 图像 echo 看到 Uint8Array

这是正常图像原始数据。看图请用：

```bash
ros2 run rqt_image_view rqt_image_view /zed/zed_node/rgb/color/rect/image
```

### 10.3 ZED 有图，但 YOLO 没输出

检查：

```bash
ros2 topic hz /zed/zed_node/rgb/color/rect/image
ros2 topic echo /perception/detections --once
ros2 run ylhb_perception yolo_detector_node --ros-args \
  -p model_path:=/home/nvidia/ros2_ws/src/ylhb_perception/models/yolo26.engine
```

如果 ZED topic 名称变化：

```bash
ros2 topic list | grep -E 'image|rgb|color|rect'
```

然后启动时覆盖：

```bash
ros2 launch ylhb_perception perception.launch.py image_topic:=真实图像topic
```

如果节点启动时直接报错，优先看：

```text
model_path 是否指向 .engine
yolo26.engine 是否是当前 Jetson 本机编译出来的
source /opt/ros/humble/setup.bash 和 source install/setup.bash 是否都执行过
```

### 10.4 优化 ONNX 模型不存在

现象：

```text
Model file does not exist:
/home/nvidia/ros2_ws/src/ylhb_perception/models/yolo26.engine
```

处理：

```text
在 PC 端把 yolo26.pt 导出为 yolo26.onnx。
把 yolo26.onnx 放到：
/home/nvidia/ros2_ws/src/ylhb_perception/models/yolo26.onnx
然后在 Jetson 端编译：
ros2 run ylhb_perception export_yolo_trt.py \
  --onnx /home/nvidia/ros2_ws/src/ylhb_perception/models/yolo26.onnx \
  --output /home/nvidia/ros2_ws/src/ylhb_perception/models/yolo26.engine \
  --workspace 2048
```

注意：

```text
开发板默认只运行 TensorRT yolo26.engine。
更换权重或输入尺寸后，在 PC 端重新导出 ONNX，并在 Jetson 端重新编译 engine。
```

### 10.5 导航时小车位置飘

重点检查：

```text
/scan 是否稳定
地图是否变形
laser_link 在 URDF 里的安装位姿是否正确
AMCL 初始位姿是否合理
```

### 10.6 有 `/cmd_vel` 但车不动

检查：

```bash
ros2 topic echo /cmd_vel
ros2 topic echo /odom --once
ros2 topic echo /zlac8015d/status
ros2 topic echo /zlac8015d/fault
ip -details link show can1
candump -tz can1
ls -l /dev/ttyS1 /dev/robot_*
```

可能原因：

```text
默认 ZLAC 后端：can1 没配置或没 up
默认 ZLAC 后端：USB-CAN/CAN 线未接、终端电阻或波特率错误
默认 ZLAC 后端：ZLAC 未上电、未使能或 /zlac8015d/fault 有非零故障
STM32 回退：底盘串口错误、STM32 没上电、base_controller 没连上串口
```

ZLAC 调试顺序：

```bash
cd ~/ros2_ws
./scripts/setup_zlac_can.sh can1 500000
ip -details link show can1
candump -tz can1
ros2 run ylhb_base zlac8015d_canopen_controller \
  --ros-args \
  --params-file src/ylhb_base/config/base_kinematics.yaml \
  --params-file src/ylhb_base/config/zlac8015d.yaml
```

`candump -tz can1` 的关键验收报文：

```text
(000.000000)  can1  701   [1]  00
```

这表示 ZLAC8015D node_id=1 已通过 PCAN-USB 在 CANopen 上电后发出 boot-up 心跳，ROS2 默认底盘后端才具备直接通信条件。无 USB-CAN 线或未收到 `701#00` 时，只能完成编译、launch 参数解析和静态验证；低速转动、`/odom` 回显、fault/status 检查必须等 CAN 线和 ZLAC 驱动器到位后执行。

### 10.7 `colcon build` 报 `canonicalize_version` 或 `setuptools` 错误

现象：

```text
TypeError: canonicalize_version() got an unexpected keyword argument 'strip_trailing_zero'
```

原因通常是用户目录 `~/.local` 里的 Python 包版本和 ROS 2 Humble 的构建工具不兼容。

处理：

```bash
cd ~/ros2_ws
PYTHONNOUSERSITE=1 bash -lc \
  'source /opt/ros/humble/setup.bash && colcon build --packages-select ylhb_interfaces ylhb_llm --symlink-install'
source install/setup.bash
```

### 10.8 source ROS 环境时报 AMENT_TRACE_SETUP_FILES

现象：

```text
/opt/ros/humble/setup.bash: line 8: AMENT_TRACE_SETUP_FILES: unbound variable
```

原因是当前 shell 启用了 `set -u`，而 ROS 2 Humble 的 setup 脚本会读取未定义变量。比赛现场优先使用包装脚本，它已经处理这个问题：

```bash
cd ~/ros2_ws
./scripts/run_on_jetson.sh competition
```

如果必须手动 source，先关闭 nounset：

```bash
set +u
source /opt/ros/humble/setup.bash
source ~/ros2_ws/install/setup.bash
```

### 10.9 大模型节点启动后图片 service 调用失败

先检查 Key：

```bash
echo $DASHSCOPE_API_KEY
```

再检查图片路径：

```bash
ls -l /home/nvidia/ros2_ws/src/ylhb_llm/test_images/
```

常见原因：

```text
DASHSCOPE_API_KEY 没设置
图片路径写错
目录内不是唯一一张 .jpg/.jpeg/.png 图片
比赛现场网络不可用
DashScope 控制台里的模型 ID 和 llm.yaml 默认值不一致
```

如果模型 ID 不一致，启动时覆盖：

```bash
ros2 launch ylhb_llm llm.launch.py \
  vl_model:=实际可用的视觉模型ID \
  chat_model:=实际可用的文本模型ID \
  enable_voice:=false \
  enable_tts:=false
```

### 10.10 图片理解成功但没有推荐商品

先看 `/perception/localized_objects`：

```bash
ros2 topic echo /perception/localized_objects --once
```

可能原因：

```text
YOLO 当前没有识别到货架商品
/perception/localized_objects 超过 2 秒没有更新，货架快照过期
YOLO class_name 还是数字，无法和 products.yaml 的商品别名匹配
products.yaml 里缺少现场商品别名
```

处理建议：

```text
先让机器人对准货架，确认 /perception/localized_objects 有当前商品。
如果 class_name 是数字，在 ylhb_perception/config/detector.yaml 里按 class_id 配好 class_names。
如果商品名称口语化不一致，在 products.yaml 的 aliases 中补别名。
```

### 10.11 语音输入没反应

先确认系统能看到 eMeet Luna：

```bash
lsusb | grep -i emeet
arecord -l
```

如果没有声卡：

```text
检查 eMeet Luna USB 是否插好
检查系统是否识别 USB 音频设备
重插后再执行 arecord -l
```

如果有声卡但不是默认设备，优先使用名字式设备：

```bash
ros2 launch ylhb_llm llm.launch.py \
  enable_voice:=true \
  enable_tts:=false \
  audio_input_device:=plughw:CARD=Luna,DEV=0
```

调试语音时先关闭 TTS，只看 ASR 是否能发布文字。触发一次录音：

```bash
ros2 service call /retail_ai/capture_voice std_srvs/srv/Trigger "{}"
```

再查看文字入口：

```bash
ros2 topic echo /retail_ai/text_command
```

### 10.12 播报重叠或没有声音

查看播报请求：

```bash
ros2 topic echo /retail_ai/say_text --once
```

查看播报状态：

```bash
ros2 topic echo /retail_ai/voice_status --once
```

没有声音时先确认启动参数：

```text
enable_voice:=true
enable_tts:=true
audio_output_device 是否正确
aplay -l 是否能看到播放设备
DASHSCOPE_API_KEY 是否设置
```

如果只想比赛调试不播放声音，可以保持：

```bash
ros2 launch ylhb_llm llm.launch.py enable_voice:=false enable_tts:=false
```

这时 `voice_output_node` 仍会在终端打印 `SAY[...]`，也能通过 `/retail_ai/say_text` 看到播报内容。

---

## 11. 旧视觉入口说明

旧文件：

```text
~/ros2_ws/src/ylhb_base/scripts/vision_node.py
```

现在只作为兼容桥：

```text
/perception/detections  -> /vision/result
/perception/target_pose -> /vision/target_pose
```

新代码建议直接使用：

```text
/perception/detections
/perception/debug_image    # 可选；本机看效果优先用 show_debug_window
/perception/localized_objects
/perception/target_pose
```

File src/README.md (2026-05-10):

# ROS2 Smart Car on Jetson

当前 ROS 2 工作区以 Jetson Orin Nano Super 本机开发、构建、运行为主，不再使用旧的 RDK X5 / PC 传板流程。

默认工作区路径是 `~/ros2_ws`。如果克隆到其他目录，运行脚本前设置：

```bash
export WS_DIR=/path/to/ros2_ws
```

## 主要目录

- `ylhb_base/`：底盘、IMU、URDF、EKF、RPLidar bringup、SLAM、Nav2
- `ylhb_perception/`：ZED 图像订阅、YOLO 优化模型推理、深度融合入口
- `zed-ros2-wrapper/`：第三方 ZED 2i ROS 2 wrapper
- `rplidar_ros-ros2/`：第三方 RPLidar ROS 2 驱动
- `PROJECT_DOC_zh.md`：当前 Jetson 本机运行文档
- `bind_usb.sh`：IMU / RPLidar 串口别名绑定脚本
- `my_map.yaml`、`my_map.pgm`：默认 Nav2 地图

## 快速开始

```bash
cd ~/ros2_ws
./scripts/install_jetson_dependencies.sh
./scripts/build_on_jetson.sh
```

`scripts/run_on_jetson.sh` 会自动加载 `/opt/ros/$ROS_DISTRO/setup.bash` 和 `install/setup.bash`。日常启动不需要手动 `source`；如果当前终端开了 `set -u`，手动 source ROS 环境可能触发 `AMENT_TRACE_SETUP_FILES: unbound variable`。

构建脚本会在 `colcon build` 阶段设置 `PYTHONNOUSERSITE=1`，避免用户级 `pip` 包覆盖 ROS/Ubuntu 构建工具。自研包验证命令：

```bash
PYTHONNOUSERSITE=1 colcon test \
  --packages-select ylhb_base ylhb_perception ylhb_llm ylhb_interfaces \
  --event-handlers console_direct+
```

ZED/RPLidar 第三方源码用于比赛部署构建；完整 `colcon test` 可能因 vendor lint 或离线 schema 校验失败，不作为自研项目质量门槛。

启动底盘、IMU、雷达、URDF、EKF：

```bash
./scripts/run_on_jetson.sh bringup
```

启动 ZED 2i：

```bash
./scripts/run_on_jetson.sh zed
```

启动视觉检测：

```bash
./scripts/run_on_jetson.sh perception \
  model_path:=/home/nvidia/ros2_ws/src/ylhb_perception/models/yolo26.engine \
  backend:=tensorrt \
  imgsz:=960 \
  confidence_threshold:=0.35 \
  max_det:=20 \
  half:=true \
  publish_debug_image:=false \
  log_interval_sec:=2.0 \
  device:=cuda:0
```

启动大模型任务层：

```bash
export DASHSCOPE_API_KEY=你的DashScopeKey
./scripts/run_on_jetson.sh llm enable_voice:=false enable_tts:=false
```

eMeet Luna 语音输入/播报：

```bash
./scripts/run_on_jetson.sh llm \
  enable_voice:=true \
  enable_tts:=true \
  audio_input_device:=plughw:CARD=Luna,DEV=0 \
  audio_output_device:=plughw:CARD=Luna,DEV=0
```

语音输入采用按钮或服务触发：

```bash
ros2 service call /retail_ai/capture_voice std_srvs/srv/Trigger "{}"
```

启动比赛现场显示屏 UI / 总控台：

```bash
./scripts/run_on_jetson.sh competition
```

`competition` 默认启用 eMeet Luna 语音输入和播报，设备为 `plughw:CARD=Luna,DEV=0`。启动后在 UI 的“系统控制”页点击“一键启动比赛节点”，由总控台启动底盘/雷达、ZED、感知和导航；不需要再手动开其它终端。若现场需要临时静音：

```bash
./scripts/run_on_jetson.sh competition enable_tts:=false
```

比赛现场物理屏幕使用 `DISPLAY=:0`，`competition` 脚本会自动覆盖 SSH X11 转发的 `DISPLAY=localhost:10.0`。远程 X11 调试时使用：

```bash
./scripts/run_on_jetson.sh competition force_local_display:=false fullscreen:=false
```

`competition` 启动时会自动关闭 X11 屏保、空白屏和 DPMS 省电息屏，避免比赛过程中显示屏自动熄灭。若需要手动确认：

```bash
DISPLAY=:0 xset q
```

`competition` 也会默认启动 IBus 拼音输入法。物理屏幕上的系统虚拟键盘仍按屏幕手势调出；项目不再额外启动 Onboard。若需要确认中文输入法：

```bash
ibus engine
ibus list-engine | grep -i pinyin
```

也可以单独启动 UI：

```bash
ros2 run ylhb_llm retail_display_ui_node
```

UI 支持任务 A/B/C/D 启动、B-1 图片预览、建图启动/停止、保存地图、导航/感知/AI 任务层启动、识别结果显示、播报文本、购物车和总价显示。

小尺寸显示屏会自动启用紧凑布局：顶部状态栏换行显示，字号和间距会缩小，主内容支持滚动，避免无边框全屏时界面被固定最小尺寸撑到屏幕外。若现场仍有显示器过扫描导致边缘被裁切，先用窗口化确认：

```bash
./scripts/run_on_jetson.sh competition fullscreen:=false
```

B-1 按钮依赖 `retail_task_node` 提供 `/retail_ai/start_b1_task`。比赛启动后等顶部 `B1服务: 就绪` 再点击；如果只单独运行 UI，不会自动拥有 B-1 服务。

任务书图片分析服务：

```bash
ros2 service call /retail_ai/start_b1_task std_srvs/srv/Trigger "{}"
```

文字任务输入：

```bash
ros2 topic pub --once /retail_ai/text_command std_msgs/msg/String "{data: '来瓶可乐'}"
ros2 topic echo /retail_ai/task_event
ros2 topic echo /retail_ai/say_text
```

启动建图：

```bash
./scripts/run_on_jetson.sh mapping
```

启动导航：

```bash
./scripts/run_on_jetson.sh navigation
```

默认导航地图：

```text
~/ros2_ws/src/my_map.yaml
```

详细说明见 `PROJECT_DOC_zh.md` 和 `../MIGRATION_JETSON.md`。

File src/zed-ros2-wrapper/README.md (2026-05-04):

<h1 align="center">
   Stereolabs<br \>
   ROS 2 包装器
</h1>

<p align="center">
  适用于 Stereolabs ZED 相机的 ROS 2 功能包。<br>
  ROS 2 Foxy Fitzroy（Ubuntu 20.04）- ROS 2 Humble Hawksbill（Ubuntu 22.04）- ROS 2 Jazzy Jalisco（Ubuntu 24.04）
</p>

<hr>

本包用于在 ROS 2 中使用 ZED 相机，提供多种数据类型，包括：

- 彩色与灰度图像（校正/未校正）
- 深度数据
- 带颜色的 3D 点云
- 定位与建图（可选 GNSS 融合）
- 传感器数据
- 目标检测结果
- 人体骨架数据
- 等更多功能...

[更多信息](https://www.stereolabs.com/docs/ros2)

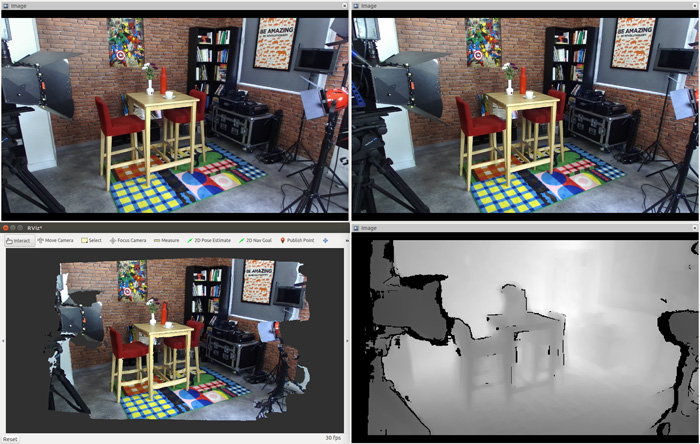
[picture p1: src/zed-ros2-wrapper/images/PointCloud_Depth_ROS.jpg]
Point_cloud


## 安装

### 前置条件

- [Ubuntu 20.04 (Focal Fossa)](https://releases.ubuntu.com/focal/)、[Ubuntu 22.04 (Jammy Jellyfish)](https://releases.ubuntu.com/jammy/) 或 [Ubuntu 24.04 (Noble Numbat)](https://releases.ubuntu.com/noble/)
- [ZED SDK](https://www.stereolabs.com/developers/release/latest/) v5.2（若需旧版本支持，请查看 [releases](https://github.com/stereolabs/zed-ros2-wrapper/releases)）
- [CUDA](https://developer.nvidia.com/cuda-downloads) 依赖
- ROS 2 Foxy Fitzroy（已弃用）、ROS 2 Humble Hawksbill 或 ROS 2 Jazzy Jalisco：
  - [Ubuntu 20.04 上的 Foxy](https://docs.ros.org/en/foxy/Installation/Linux-Install-Debians.html) [**不推荐，已 EOL**]
  - [Ubuntu 22.04 上的 Humble](https://docs.ros.org/en/humble/Installation/Linux-Install-Debians.html) [EOL：2027 年 5 月]
  - [Ubuntu 24.04 上的 Jazzy](https://docs.ros.org/en/jazzy/Installation/Linux-Install-Debians.html) [EOL：2029 年 5 月]

> 📝 **讲解注释：**
> - 推荐优先使用 **Humble/Jazzy**，Foxy 已停止维护。
> - ZED SDK 与 CUDA 版本匹配很关键，版本不一致常导致编译/运行失败。

### 构建包

**zed_ros2_wrapper** 是一个 [colcon](http://design.ros2.org/articles/build_tool.html) 包。

> :pushpin: **说明：** 如果你还没有配置 colcon 工作空间，请先参考这个简短[教程](https://index.ros.org/doc/ros2/Tutorials/Colcon-Tutorial/)。

安装 **zed_ros2_wrapper**，打开终端并执行：

```bash
mkdir -p ~/ros2_ws/src/ # 若工作空间不存在则创建
cd ~/ros2_ws/src/ # 进入你的 ROS 2 工作空间 src 目录
git clone https://github.com/stereolabs/zed-ros2-wrapper.git
cd ..
sudo apt update
rosdep update
rosdep install --from-paths src --ignore-src -r -y # 安装依赖
colcon build --symlink-install --cmake-args=-DCMAKE_BUILD_TYPE=Release --parallel-workers $(nproc) # 编译工作空间
echo source $(pwd)/install/local_setup.bash >> ~/.bashrc # 可选：每次新终端自动 source
source ~/.bashrc
```

> 📝 **讲解注释：**
> - `rosdep install` 会自动解析并安装 ROS 依赖。
> - `--symlink-install` 便于开发调试（修改脚本/配置后通常无需重新完整编译）。
> - `--parallel-workers $(nproc)` 使用所有 CPU 核心加速编译。

> :pushpin: **说明：** 依赖 `zed_msgs` 不再作为本仓库子模块安装；在 ROS 2 Humble 下可通过 `apt` 安装二进制包。若使用 Foxy 或其他发行版，可从 [zed-ros2-interfaces 仓库](https://github.com/stereolabs/zed-ros2-interfaces?tab=readme-ov-file#install-the-package-from-the-source-code)源码安装。

> :pushpin: **说明：** 若缺少 `rosdep`，可安装：
>
> `sudo apt-get install python3-rosdep python3-rosinstall-generator python3-vcstool python3-rosinstall build-essential`

> :pushpin: **说明：** `zed_debug` 包仅用于内部开发；如果不需要，可在 `colcon` 命令中添加 `--packages-skip zed_debug` 跳过编译。

> :pushpin: **说明：** 在 NVIDIA Jetson（JP6）上首次编译可能出现如下错误：
>
> ```bash
> CMake Error at /usr/share/cmake-3.22/Modules/FindCUDA.cmake:859 (message):
>   Specify CUDA_TOOLKIT_ROOT_DIR
> Call Stack (most recent call first):
>  /usr/local/zed/zed-config.cmake:72 (find_package)
>  CMakeLists.txt:81 (find_package)
> ```
>
> 可通过安装缺失的 `nvidia-jetpack` 包修复：
>
> `sudo apt install nvidia-jetpack nvidia-jetpack-dev`

> :pushpin: **说明：** `--symlink-install` 非常重要。ROS 2 包安装时通常会复制文件到 install 目录；启用软链接后，对“无需编译”的文件（Python、配置等）直接修改即可在下次运行生效，无需重新 `colcon build`。

> :pushpin: **说明：** 如果你使用 zsh，请改为：
> `echo source $(pwd)/install/local_setup.zsh >> ~/.zshrc`，然后 `source ~/.zshrc`。

## 启动 ZED 节点

> :pushpin: **说明：** 建议先阅读这份 [ROS 2 调优指南](https://www.stereolabs.com/docs/ros2/dds_and_network_tuning)，可改善 ZED 在 ROS 2 下的通信与性能。

启动命令：

```bash
ros2 launch zed_wrapper zed_camera.launch.py camera_model:=<camera_model>
```

将 `<camera_model>` 替换为你的相机型号：  
`'zed'`, `'zedm'`, `'zed2'`, `'zed2i'`, `'zedx'`, `'zedxm'`, `'zedxhdrmini'`, `'zedxhdr'`, `'zedxhdrmax'`, `'virtual'`, `'zedxonegs'`, `'zedxone4k'`, `'zedxonehdr'`。

`zed_camera.launch.py` 是 Python launch 脚本，使用“手动组合”（["manual composition"](https://index.ros.org/doc/ros2/Tutorials/Composition/)）自动启动 ZED 节点，并按相机型号加载对应 YAML 参数。  
同时会启动 Robot State Publisher，发布与该相机 URDF 模型匹配的静态链接与关节。

> :pushpin: **说明：** 你可以在 `zed_wrapper/config` 下修改配置文件：
> **common_stereo.yaml**、**zed.yaml**、**zedm.yaml**、**zed2.yaml**、**zed2i.yaml**、**zedx.yaml**、**zedxm.yaml**、**common_mono.yaml**、**zedxonegs.yaml**、**zedxone4k.yaml**、**zedxonehdr.yaml**。

查看全部可用 launch 参数：

```bash
ros2 launch zed_wrapper zed_camera.launch.py -s
ros2 launch zed_display_rviz2 display_zed_cam.launch.py -s
```

参数完整说明见[文档](https://www.stereolabs.com/docs/ros2/zed_node#configuration-parameters)。

### RViz 可视化

可在 [`zed-ros2-examples` 仓库](https://github.com/stereolabs/zed-ros2-examples/tree/master/zed_display_rviz2)使用预配置 RViz 环境，查看各类 ZED 数据与高级示例（深度、点云、里程计、目标检测等）。

也可快速验证深度数据：

```bash
rviz2 -d ./zed_wrapper/config/rviz2/<your camera model>.rviz
```

> 📝 **讲解注释：** RViz 会订阅大量话题，可能降低整体运行性能。性能测试建议在不启 RViz 时进行。

### 仿真模式

> :pushpin: **说明：** 此功能不兼容 ZED X One 和第一代旧款 ZED 相机。

使用仿真输入启动独立 ZED ROS 2 节点：

```bash
ros2 launch zed_wrapper zed_camera.launch.py camera_model:=zedx sim_mode:=true
```

启动参数：

- [必选] `camera_model`：仿真相机型号，必须与仿真设备一致。
- [必选] `sim_mode`：若为 `true`，以仿真模式启动。
- [可选] `use_sim_time`：等待 `/clock` 有效消息并使用仿真时钟。
- [可选] `sim_address`：仿真服务器地址，默认 `127.0.0.1`（同机部署常用）。
- [可选] `sim_port`：仿真服务器端口，需与 `ZED camera streamer` 节点的 `Streaming Port` 一致。多相机仿真时，每个相机需不同端口。

也可直接启动带可视化的预配置 RViz：

```bash
ros2 launch zed_display_rviz2 display_zed_cam.launch.py camera_model:=zedx sim_mode:=true
```

`display_zed_cam.launch.py` 内部包含了 `zed_camera.launch.py`，因此参数一致可复用。

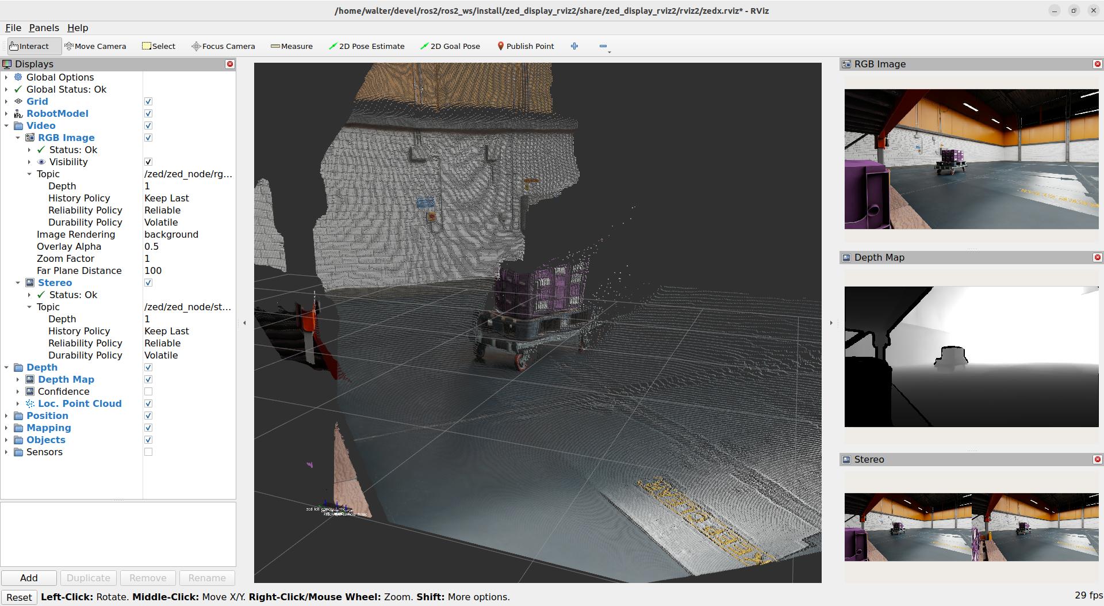
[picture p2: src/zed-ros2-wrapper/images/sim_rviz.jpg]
Sim RVIZ2


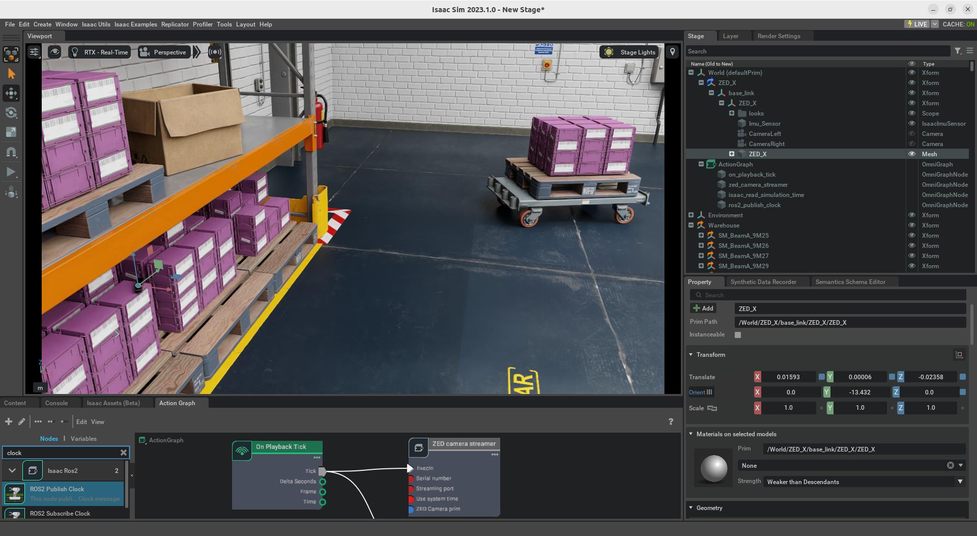
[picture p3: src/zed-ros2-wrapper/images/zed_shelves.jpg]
Shelves


支持的仿真环境：

- [NVIDIA Omniverse Isaac Sim](https://www.stereolabs.com/docs/isaac-sim/)

## 更多功能

### Point Cloud Transport（点云传输）

ZED ROS 2 Wrapper 支持 [Point Cloud Transport](http://wiki.ros.org/point_cloud_transport)，可用不同压缩方式发布点云。

仅当 ROS 2 环境中安装了 `point_cloud_transport` 包时可用；否则会自动禁用。

安装命令：

```bash
sudo apt install ros-$ROS_DISTRO-point-cloud-transport ros-$ROS_DISTRO-point-cloud-transport-plugins
```

:pushpin: **说明：** `point_cloud_transport` 不再是强制依赖，以避免所有环境都必须安装；如需该特性请手动安装。

### SVO 录制

节点运行时可通过服务 `start_svo_recording` 与 `stop_svo_recording` 启停 [SVO 录制](https://www.stereolabs.com/docs/video/recording/)。  
[更多信息](https://www.stereolabs.com/docs/ros2/zed_node/#services)

### 目标检测（Object Detection）

> :pushpin: **说明：** 此功能不兼容 ZED X One 和第一代旧款 ZED 相机。

可在启动时自动启用：在 `common_stereo.yaml` 中将 `object_detection/od_enabled` 设为 `true`。  
也可运行中通过服务 `enable_obj_det` 手动启停。

详细说明见[文档](https://www.stereolabs.com/docs/ros2/object-detection)。

### 使用 YOLO-like ONNX 的自定义目标检测

> :pushpin: **说明：** 此功能不兼容 ZED X One 和第一代旧款 ZED 相机。

可使用 YOLO-like ONNX 格式模型进行自定义推理。

安装 Ultralytics YOLO 工具：

```bash
python -m pip install ultralytics
```

已安装可升级：

```bash
pip install -U ultralytics
```

导出 ONNX（示例）：

```bash
yolo export model=yolo11n.pt format=onnx simplify=True dynamic=False imgsz=640
```

自训练模型示例：

```bash
yolo export model=yolov8l_custom_model.pt format=onnx simplify=True dynamic=False imgsz=512
```

详情见 [Ultralytics 文档](https://github.com/ultralytics/ultralytics)。

修改 `common_stereo.yaml`：

- 将 `object_detection.model` 设为 `CUSTOM_YOLOLIKE_BOX_OBJECTS`

并根据实际情况调整 `custom_object_detection.yaml`。

> :pushpin: **说明：** 首次使用自定义模型时，ZED SDK 会针对当前 GPU 执行优化，可能耗时数分钟。Docker 场景建议使用宿主机共享卷保存优化结果，避免重复优化。

优化期间日志示例：

```bash
[zed_wrapper-3] [INFO] [1729184874.634985183] [zed.zed_node]: === Starting Object Detection ===
[zed_wrapper-3] [2024-10-17 17:07:55 UTC][ZED][INFO] Please wait while the AI model is being optimized for your graphics card
[zed_wrapper-3]  This operation will be run only once and may take a few minutes 
```

详细说明见[文档](https://www.stereolabs.com/docs/ros2/custom-object-detection)。

### 人体跟踪（Body Tracking）

> :pushpin: **说明：** 此功能不兼容 ZED X One 和第一代旧款 ZED 相机。

可在启动时自动启用：在 `common_stereo.yaml` 中将 `body_tracking/bt_enabled` 设为 `true`。

### 空间建图（Spatial Mapping）

> :pushpin: **说明：** 此功能不兼容 ZED X One 相机。

可在启动时自动启用：在 `common_stereo.yaml` 中将 `mapping/mapping_enabled` 设为 `true`。  
也可运行中通过服务 `enable_mapping` 手动启停。

### GNSS 融合

> :pushpin: **说明：** 此功能不兼容 ZED X One 相机。

ZED ROS 2 Wrapper 可订阅 `NavSatFix` 话题，并将 GNSS 信息与视觉定位融合，得到以地球坐标为参考的精准定位。  
启用方式：设置 `gnss_fusion.gnss_fusion_enabled` 为 `true`。  
启动时需设置正确 `gnss_frame`，例如：`gnss_frame:='gnss_link'`。  
服务 `toLL` 和 `fromLL` 可在经纬度与机器人 `map` 坐标之间转换。

### 2D 模式

> :pushpin: **说明：** 此功能不兼容 ZED X One 相机。

对于平面运动机器人，可启用 2D 模式（`common_stereo.yaml` 中 `pos_tracking/two_d_mode`）。  
里程计与位姿中的 Z 坐标固定为 `pos_tracking/fixed_z_value`；Roll/Pitch 与对应速度固定为 0。

## NVIDIA® Isaac ROS 集成

ZED ROS 2 Wrapper 与 [NVIDIA® Isaac ROS](https://nvidia-isaac-ros.github.io/) 兼容。  
该框架为 NVIDIA 平台机器人应用提供工具与库。

本包装器可利用 [NITROS](https://nvidia-isaac-ros.github.io/concepts/nitros/index.html)（NVIDIA® Isaac Transport for ROS）在 NVIDIA 加速 ROS 图中实现高效数据流。

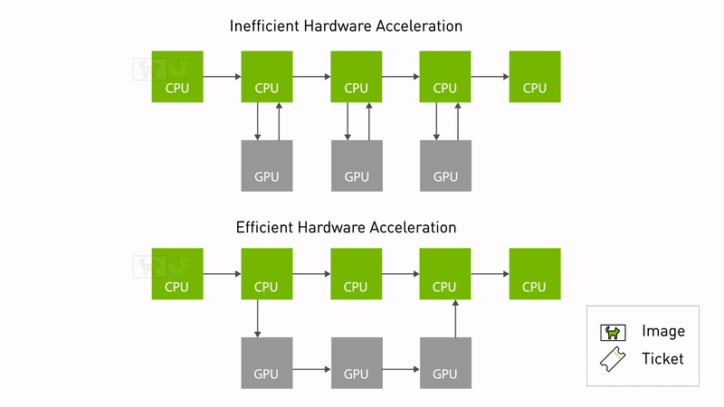
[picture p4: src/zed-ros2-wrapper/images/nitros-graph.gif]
NITROS communication


请阅读完整 [Isaac ROS 集成指南](https://docs.stereolabs.com/isaac-ros/)，了解如何配置开发环境。

## 示例与教程

为帮助理解与集成，示例与教程位于 [`zed-ros2-examples` 仓库](https://github.com/stereolabs/zed-ros2-examples)。

### RVIZ2 可视化示例

- 预配置 RViz 启动文件（显示 ZED Wrapper 节点全部信息）：[zed_display_rviz2](https://github.com/stereolabs/zed-ros2-examples/tree/master/zed_display_rviz2)
- ZED2 的 ROS 2 RViz 插件（显示目标检测框与骨架）：[rviz-plugin-zed-od](https://github.com/stereolabs/zed-ros2-examples/tree/master/rviz-plugin-zed-od)
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

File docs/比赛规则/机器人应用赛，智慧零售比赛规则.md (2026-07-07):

一、项目设置背景
随着科技的飞速发展，人工智能技术已经成为推动各行业转型升
级的重要引擎，特別是大模型技术，“基于大模型的智慧零售”竞赛
项目，旨在通过实际操作和竞技，探索大模型与机器人在智慧零售领
域的深度融合与创新应用，促进大模型技术在智慧零售领域的垂直应
用落地。
同时，机械臂作为智慧零售的重要执行工具，其精准、高效、自
动化的特点与大模型的智能化决策能力相得益彰，共同推动智慧零售
的快速发展。
本次竞赛项目将要求学生综合运用大模型技术和机器人技术，完
成一系列智慧零售场景下的实际任务：大模型的部署及应用、机器人
运动控制、建图及导航、语音交互、机器视觉、物品识别及抓取等。
通过该赛项，学生不仅能够深入了解大模型和智能机器人技术的原理
和应用，还能够锻炼其大模型的应用、算法设计、系统集成等方面的
能力。
二、 项目进行方式
线上和线下。
本规则同时适用于线上和线下比赛，其中，线上比赛参赛事宜及注
意事项详见本赛规第四条即线上比赛方案。
三、项目规则
参加本比赛的队伍需遵循大赛总规则。
1、参赛设备技术参数要求
（1）机械臂：机械臂自由度≥6个，机械臂控制器集成于机械臂，与机
第二十八届中国机器人及人工智能大赛比赛规则
134
械臂一体设计。
（2）视觉：配备深度摄像头。
（3）移动机器人：底盘搭配激光雷达，另外还需搭载语音模块、喇叭、
显示屏等。
（4）线上和线下比赛参赛设备需选手自备，以下是参赛设备参考示意图：
图3-1赛设备参考示意图
2、比赛场景介绍
说明：线下比赛场景工位由赛项组织方搭建，具体以赛项组织方搭
建实际场景为准，线上比赛场景由参赛队伍按图3-2自行搭建。
（1）智慧零售竞赛场景每个工位尺寸为：3m×3m，每个工位由起点区S、
货架区A、结算区B三个区组成；其中货架区A放置1个货架，货架上
摆放有矿泉水、可乐、薯片、牛奶等商品清单里的商品，商品清单里的
商品会由赛项组织方提供；结算区B布置结算台1个，台面上贴有结算
区域（结算区域具体尺寸以现场提供的为准）。以下是智慧零售竞赛场景
工位示意图：
第二十八届中国机器人及人工智能大赛比赛规则
135
图3-2智慧零售竞赛场景工位的示意图
（2）货架上实际摆放物品从商品清单及价格表（表3-1）中选取，每
层摆放5个物品（一个商品类可能有多个），货架有2层，共摆放10个
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

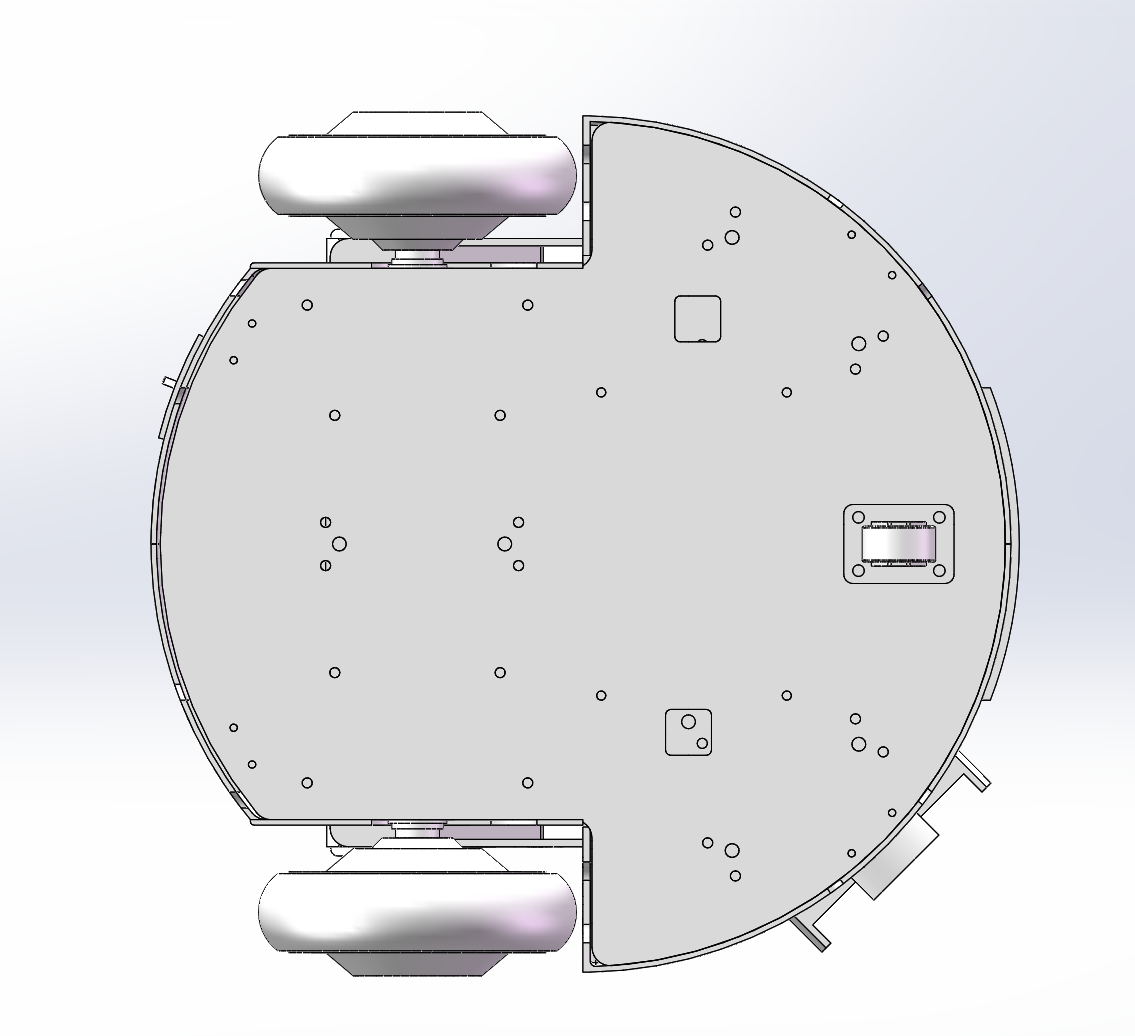
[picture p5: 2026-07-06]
CAD/Retail-Cart-3D-Model/picture/仰视图.png

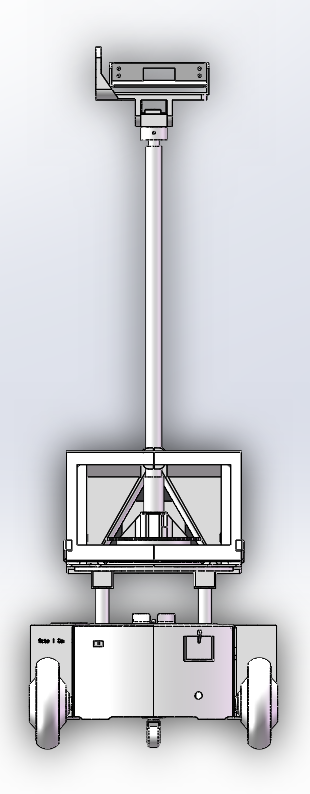
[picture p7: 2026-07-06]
CAD/Retail-Cart-3D-Model/picture/正视图.png

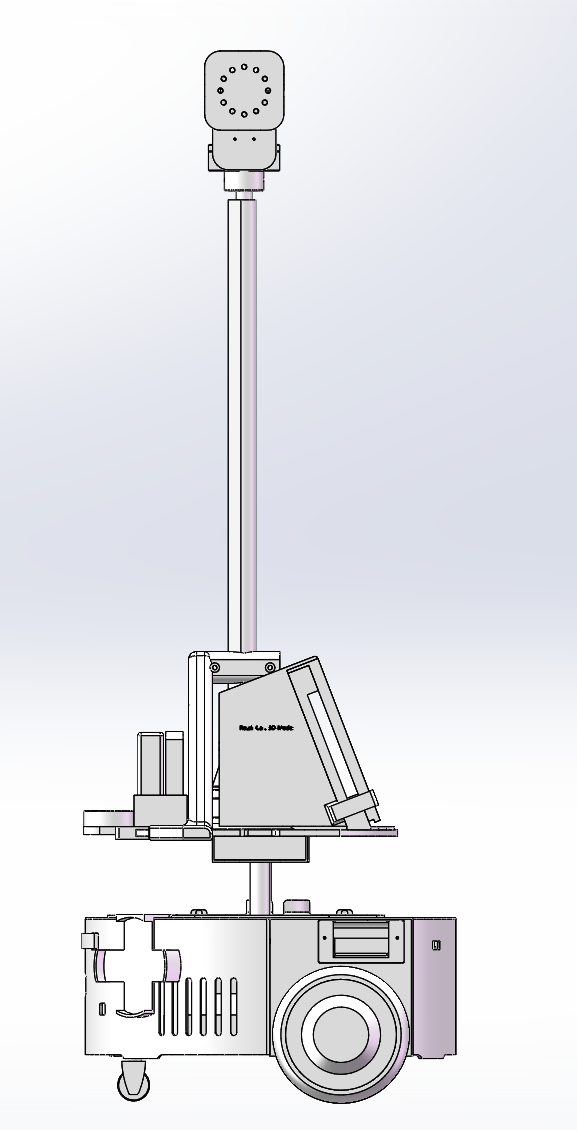
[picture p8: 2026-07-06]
CAD/Retail-Cart-3D-Model/picture/右视图.png

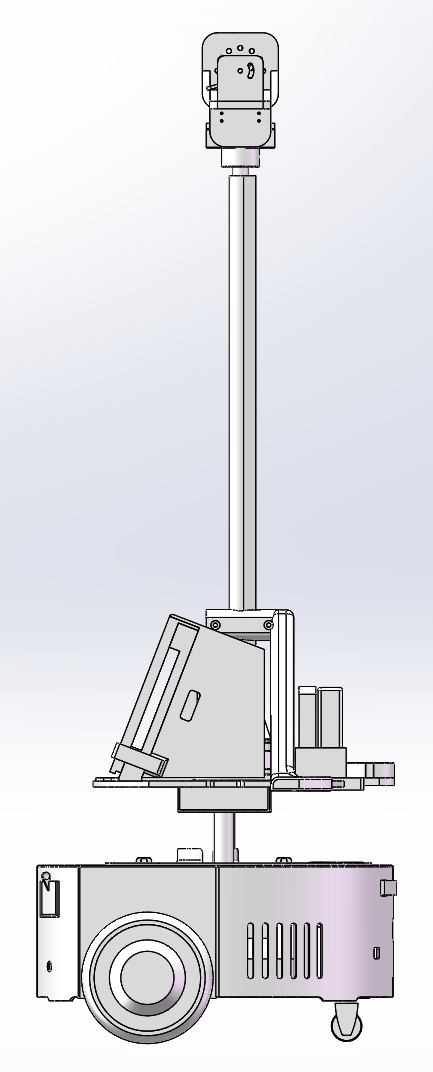
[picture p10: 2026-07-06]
CAD/Retail-Cart-3D-Model/picture/左视图.png

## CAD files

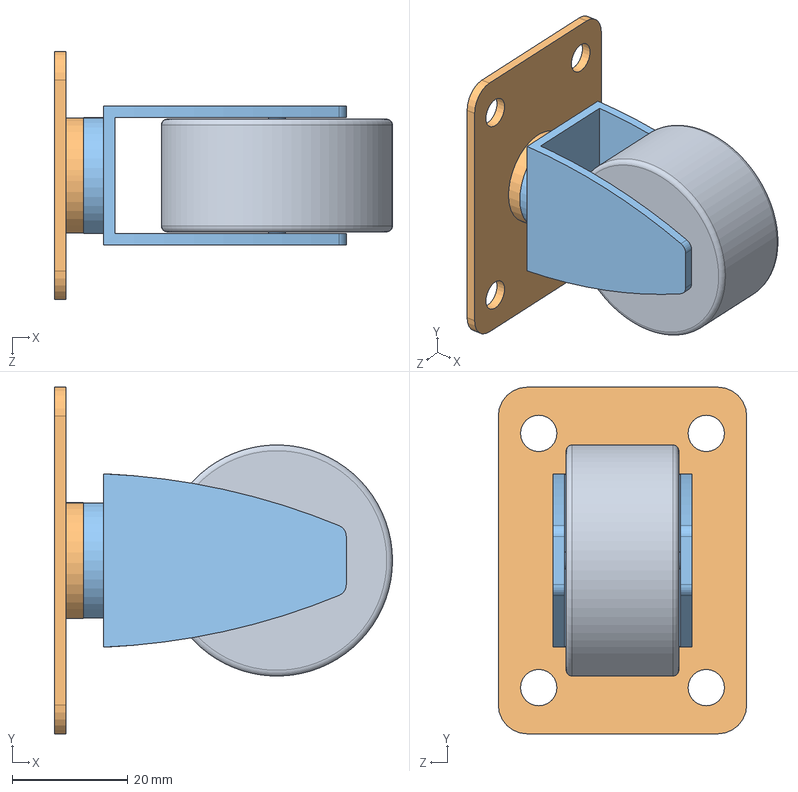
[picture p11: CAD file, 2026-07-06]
CAD/Retail-Cart-3D-Model/sldasm/万向轮.SLDASM
58.5 x 60.0 x 43.0 mm
万向轮
万向轮底座
万向轮支架

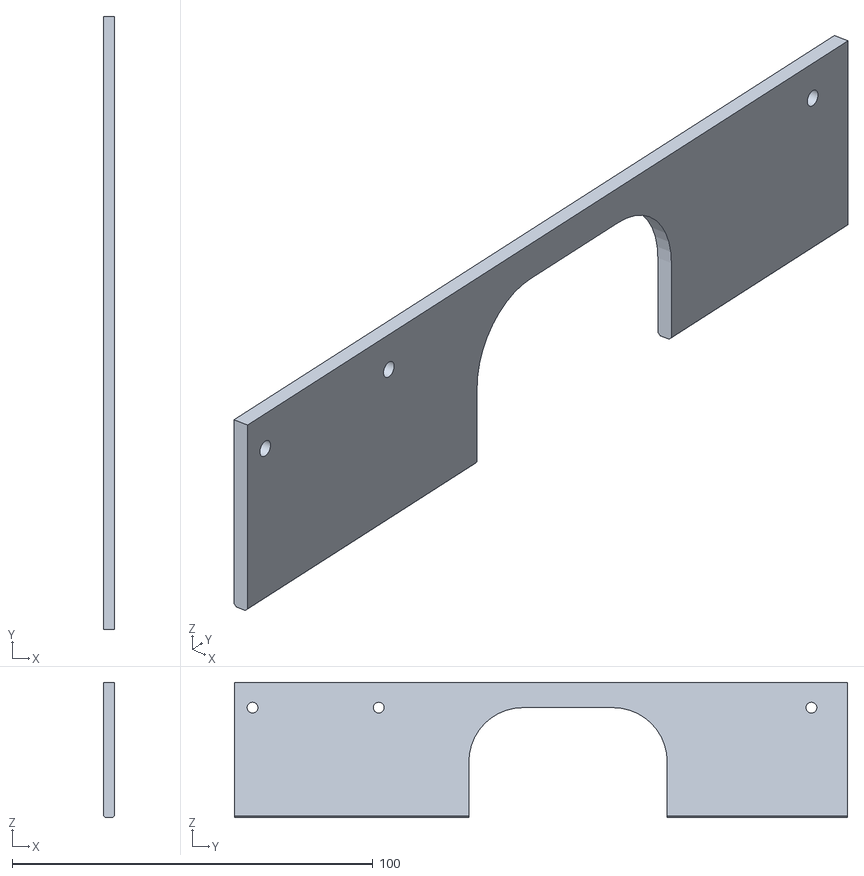
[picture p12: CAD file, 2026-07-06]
CAD/Retail-Cart-3D-Model/stl/小车底盘 - 前后半圆连接件-2.STL
3.00 x 170.0 x 37.5

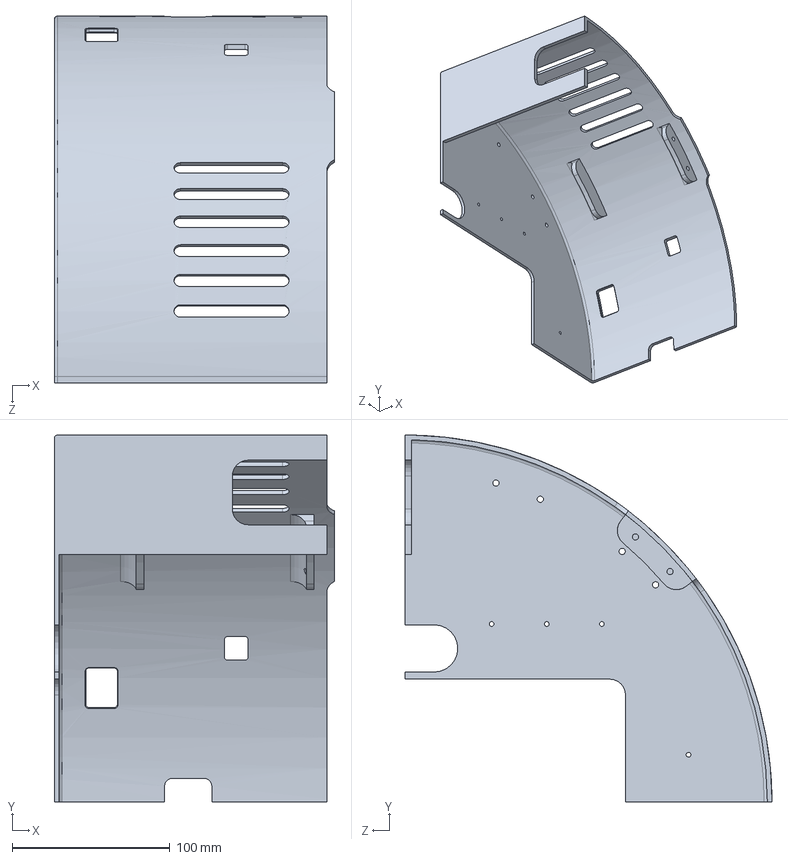
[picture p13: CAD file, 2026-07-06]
CAD/Retail-Cart-3D-Model/stp/后半圆X.SLDPRT
178.0 x 233.0 x 233.0 mm

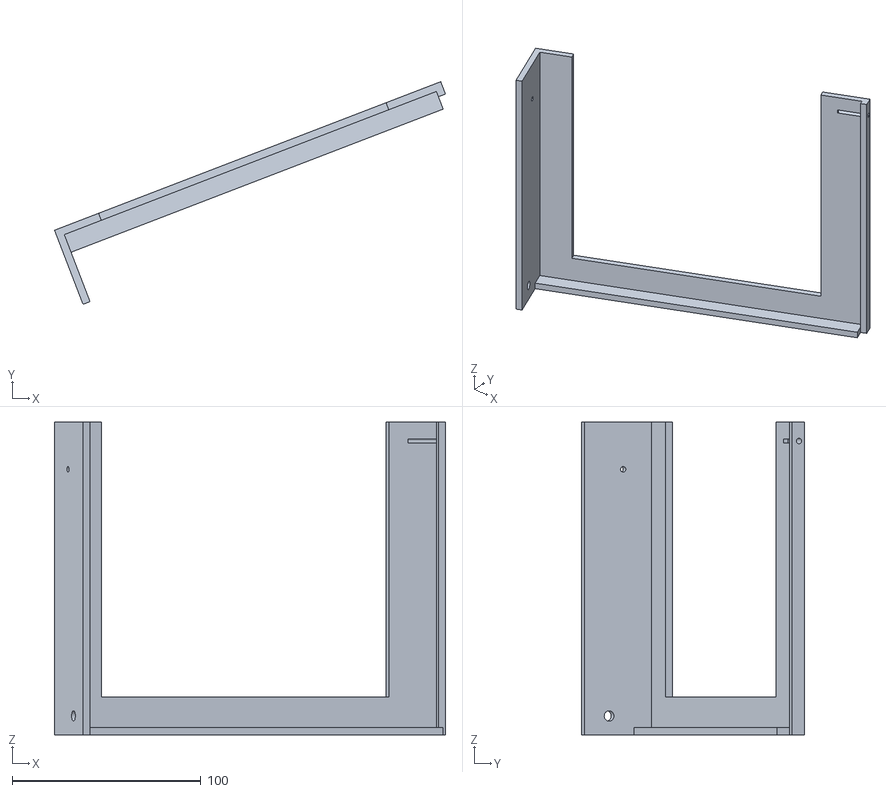
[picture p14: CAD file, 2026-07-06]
CAD/Retail-Cart-3D-Model/stl/小车底盘 - 屏幕壳子左-3.STL
206.9 x 117.8 x 165.5

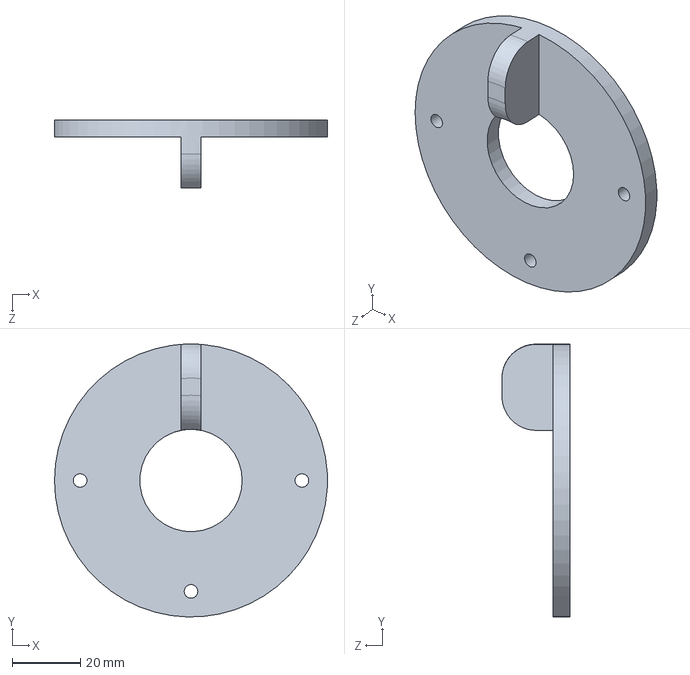
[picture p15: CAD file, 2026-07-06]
CAD/Retail-Cart-3D-Model/stp/关节盖子.SLDPRT
80.0 x 80.0 x 20.0 mm

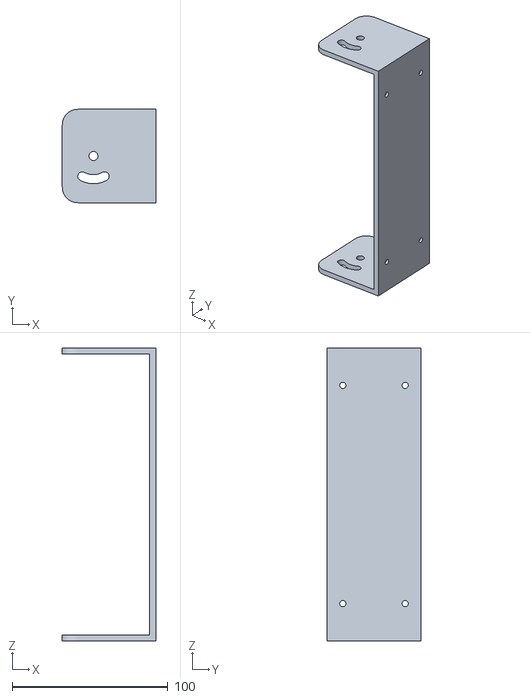
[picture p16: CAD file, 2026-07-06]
CAD/Retail-Cart-3D-Model/stl/小车底盘 - 双目架-2.STL
60.0 x 60.0 x 188.0

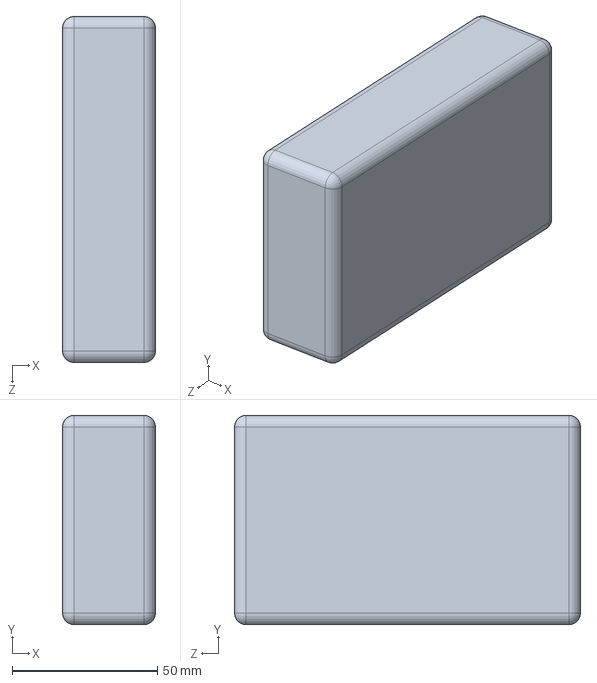
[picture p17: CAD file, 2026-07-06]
CAD/Retail-Cart-3D-Model/stp/充电宝电源.SLDPRT
32.0 x 72.0 x 119.0 mm

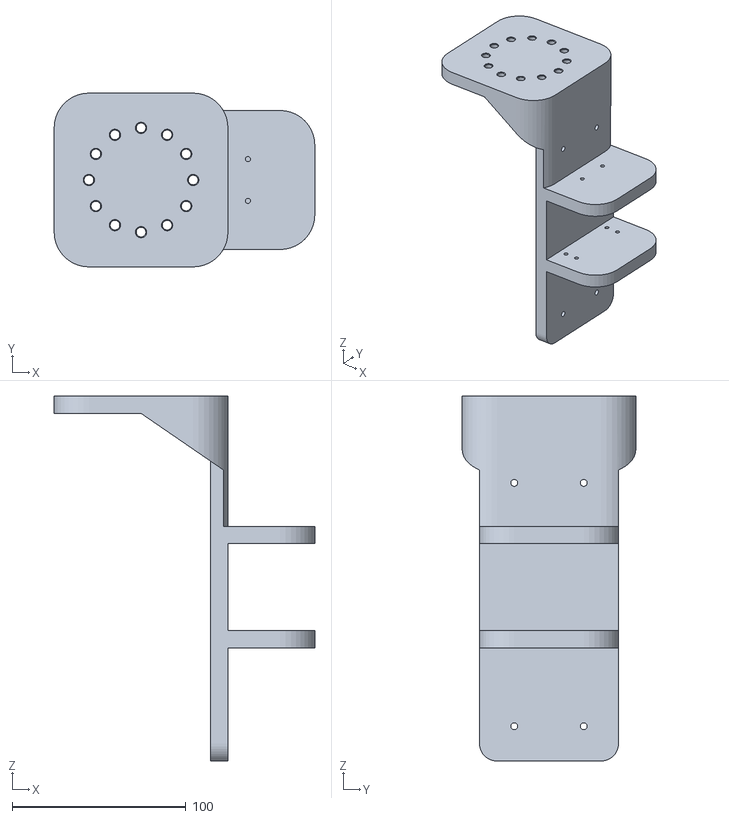
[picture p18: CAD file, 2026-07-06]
CAD/Retail-Cart-3D-Model/stl/小车底盘 - 机械臂支架-1.STL
150.0 x 100.0 x 210.0

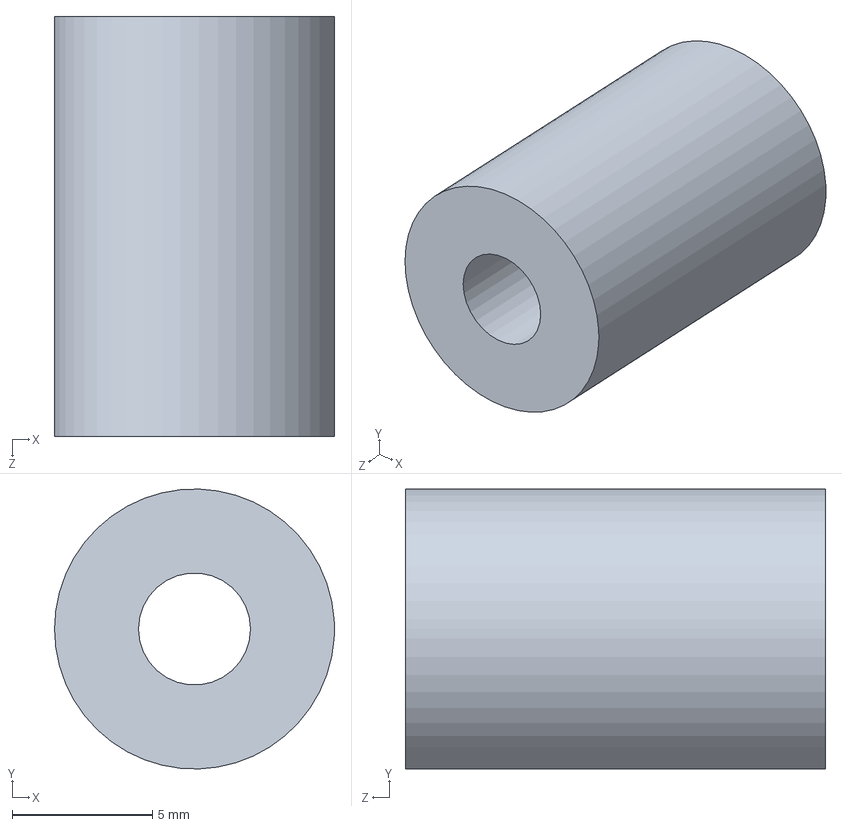
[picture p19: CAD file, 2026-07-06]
CAD/Retail-Cart-3D-Model/stp/垫高柱.SLDPRT
10.0 x 9.99 x 15.0 mm

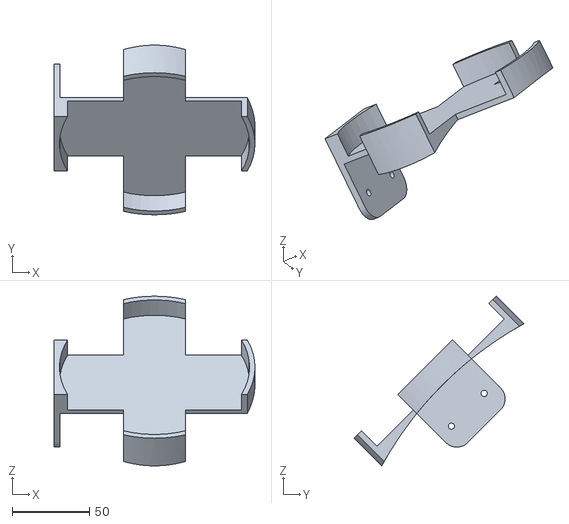
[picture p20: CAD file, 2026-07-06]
CAD/Retail-Cart-3D-Model/stl/小车底盘 - 语音播报模块外挂支架-2.STL
130.0 x 109.8 x 109.8

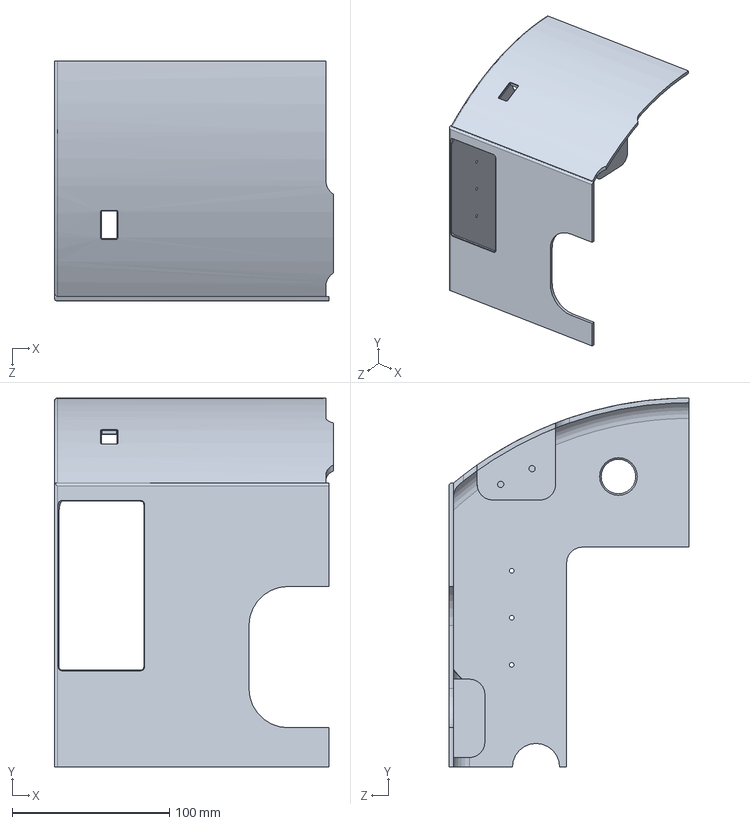
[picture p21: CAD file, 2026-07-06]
CAD/Retail-Cart-3D-Model/stp/前半圆.SLDPRT
178.0 x 235.0 x 153.0 mm

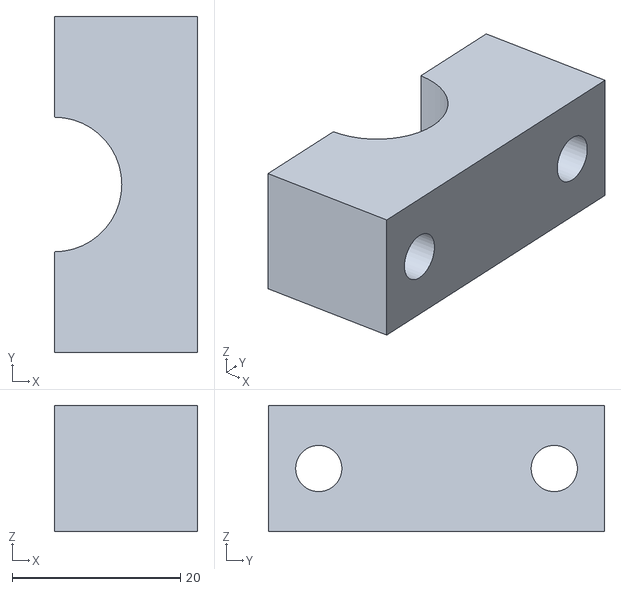
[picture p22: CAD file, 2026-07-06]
CAD/Retail-Cart-3D-Model/stl/小车底盘 - 固定盖-1.STL
17.0 x 40.0 x 15.0

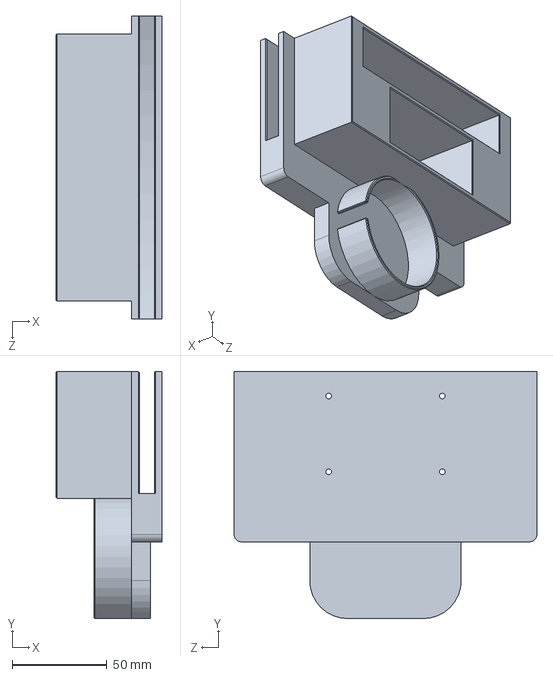
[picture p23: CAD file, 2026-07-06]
CAD/Retail-Cart-3D-Model/stp/放置电源架.SLDPRT
56.0 x 130.5 x 160.0 mm

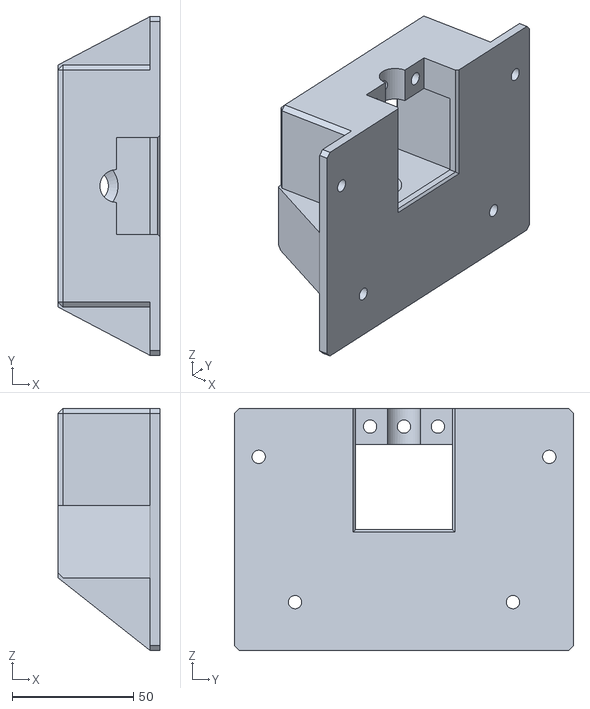
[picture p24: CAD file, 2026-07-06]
CAD/Retail-Cart-3D-Model/stl/小车底盘 - 底盘连接处支架X-1.STL
42.0 x 140.0 x 100.0

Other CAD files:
CAD/Retail-Cart-3D-Model/sldasm/机械爪.SLDASM
CAD/Retail-Cart-3D-Model/sldasm/小车底盘.SLDASM
CAD/Retail-Cart-3D-Model/stp/小北斗模块.SLDPRT
CAD/Retail-Cart-3D-Model/stl/小车底盘 - 英伟达固定板X-1.STL
CAD/Retail-Cart-3D-Model/stl/前半圆.STL
CAD/Retail-Cart-3D-Model/stl/前半圆X.STL
CAD/Retail-Cart-3D-Model/stl/后半圆.STL
CAD/Retail-Cart-3D-Model/stl/后半圆X.STL
CAD/Retail-Cart-3D-Model/stl/固定盖.STL
CAD/Retail-Cart-3D-Model/stl/小车底盘 - 万向轮-1 万向轮-1.STL
CAD/Retail-Cart-3D-Model/stl/小车底盘 - 万向轮-1 万向轮底座-1.STL
CAD/Retail-Cart-3D-Model/stl/小车底盘 - 万向轮-1 万向轮支架-1.STL
CAD/Retail-Cart-3D-Model/stl/小车底盘 - 上底盘-1.STL
CAD/Retail-Cart-3D-Model/stl/小车底盘 - 人工智能小车底盘-1.STL
CAD/Retail-Cart-3D-Model/stl/小车底盘 - 伸缩杆固定底座-1.STL
CAD/Retail-Cart-3D-Model/stl/小车底盘 - 伸缩杆支架盖子-1.STL
CAD/Retail-Cart-3D-Model/stl/小车底盘 - 前半圆-2.STL
CAD/Retail-Cart-3D-Model/stl/小车底盘 - 前半圆X-1.STL
CAD/Retail-Cart-3D-Model/stl/小车底盘 - 前后半圆连接件-1.STL
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

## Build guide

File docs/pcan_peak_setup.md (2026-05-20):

# Jetson 上 PEAK PCAN-USB 的 SocketCAN 排查与安装

这份文档用于最小侵入地排查 PEAK PCAN-USB。除非已经确认 PCAN 适配器以 SocketCAN 网络接口出现，并且能看到 ZLAC8015D 的 CANopen 启动报文，否则不要修改 ROS2 功能代码，也不要修改 `src/ylhb_base/config/zlac8015d.yaml`。

## 禁止项

诊断阶段不要执行这些操作：

- 不重编译或替换 kernel `Image`。
- 不修改 `/boot/extlinux/extlinux.conf`。
- 不添加旧版 apt 源。
- 不在临时 `insmod` 验证成功、并审核安装计划前执行 `make install`。
- 如果 PCAN 只暴露为 PEAK 字符设备，不修改 ROS2 CAN 配置。

## 基线诊断

先运行仓库里的诊断脚本：

```bash
cd ~/ros2_ws
./scripts/diagnose_pcan.sh
```

重点确认这些信号：

- `lsusb` 能看到 PEAK USB 设备，例如 `0c72:000c`。
- 当前内核配置中 `CONFIG_CAN_PEAK_USB` 未启用。
- 现有 `can0` 可能是 Jetson `mttcan`，不是 PCAN-USB。
- `/lib/modules/$(uname -r)/build` 存在，说明可以编译外部驱动模块。

如果脚本因为文件缺失、grep 无匹配、`sudo dmesg` 权限等原因输出 `WARN`，这属于诊断信息，不代表脚本提前失败。

## 准备 PEAK 驱动源码

假设 `peak-linux-driver-8.15.2.tar.gz` 已经放在 `./peak-linux-driver-8.15.2.tar.gz` 或 `~/Downloads/peak-linux-driver-8.15.2.tar.gz`。只把它解压到 `~/drivers/pcan`：

```bash
mkdir -p ~/drivers/pcan
cd ~/drivers/pcan

tar -xzf ~/Downloads/peak-linux-driver-8.15.2.tar.gz
# 如果压缩包就在当前目录：
# tar -xzf ./peak-linux-driver-8.15.2.tar.gz
```

进入解压后的驱动目录：

```bash
cd ~/drivers/pcan/peak-linux-driver-8.15.2
```

编译前必须先查看构建选项：

```bash
make help || true
grep -R "NETDEV\|SOCKETCAN\|SocketCAN\|pcaninfo" -n README* Makefile driver
```

优先使用 SocketCAN/netdev 模式。先尝试：

```bash
make clean
make NET=NETDEV_SUPPORT
```

如果 README 或 Makefile 明确说明这个版本使用其他 SocketCAN/netdev 变量，则按文档中发现的选项替代。

## 只做临时加载

此时不要执行 `make install`。只从编译目录临时加载模块：

```bash
sudo insmod ./driver/pcan.ko
```

如果实际 `.ko` 路径不同，按驱动文档或编译输出中发现的路径执行。

临时加载后检查：

```bash
ip -br link
pcaninfo || true
sudo dmesg | grep -i -E "PCAN-USB|attached|peak|pcan"
```

硬门槛是 `ip -br link` 必须出现 `can1`。

如果系统只出现类似 `/sys/class/pcan/pcanusb32`，但没有 `can1`，立即停止。这说明当前是 PEAK 字符设备模式，不是 SocketCAN。不要修改 ROS2 代码，也不要修改 `zlac8015d.yaml`。

## 启动 can1 并验证 ZLAC8015D

只有 `can1` 存在时才继续：

```bash
sudo ip link set can1 down
sudo ip link set can1 type can bitrate 500000 berr-reporting on restart-ms 100
sudo ip link set can1 up
candump -tz can1
```

保持 `candump` 运行，然后给 ZLAC8015D 重新上电。必须看到启动报文：

```text
701#00
```

只有确认 `can1` 收到 `701#00` 后，才允许进入安装建议阶段。

## 安装门槛

收到 `701#00` 后，先生成并审核安装计划：

```bash
sudo make -n install | tee ~/pcan_make_install_plan.txt
```

检查 `~/pcan_make_install_plan.txt`。只有确认安装计划符合预期、只涉及目标驱动模块和相关工具后，才考虑执行：

```bash
sudo make install
```

## 回滚

如需回滚临时接口、模块或误加的自动加载配置：

```bash
sudo ip link set can1 down || true
sudo rmmod pcan || true
sudo rm -f /etc/modules-load.d/pcan.conf
sudo depmod -a
```

## ROS2 后续

只有在稳定接口最终确认为 `can1` 后，才修改 ZLAC8015D 配置：

```yaml
can_interface: can1
```

然后重新构建受影响包：

```bash
cd ~/ros2_ws
colcon build --packages-select ylhb_base
```

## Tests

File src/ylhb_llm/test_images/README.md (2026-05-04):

# 大模型本地图片测试目录

把任务书图片放在这个目录下，例如：

```text
/home/nvidia/ros2_ws/src/ylhb_llm/test_images/task_b.png
```

启动大模型任务层：

```bash
cd ~/ros2_ws
source /opt/ros/humble/setup.bash
source install/setup.bash
export DASHSCOPE_API_KEY="你的真实DashScope_API_Key"
ros2 launch ylhb_llm llm.launch.py enable_voice:=false enable_tts:=false
```

目录内只保留一张 `.jpg/.jpeg/.png` 任务书图片，然后启动 B-1：

```bash
ros2 service call /retail_ai/start_b1_task std_srvs/srv/Trigger "{}"
```

查看播报文本：

```bash
ros2 topic echo /retail_ai/say_text --once
```

图片理解播报的预期风格是 2 到 3 个短句：先说明画面中可见的人物、表情、动作或思考气泡，再自然推断需求。例如“这张图像展示了一个看起来口渴的卡通男孩。他的舌头伸出，思考气泡中有一杯水，暗示他想要喝水。”不要让模型只输出一句夸张结论。

测试文字购物和本地价格计算：

```bash
ros2 topic pub --once /retail_ai/text_command std_msgs/msg/String "{data: '来瓶可乐'}"
ros2 topic echo /retail_ai/task_event --once
```

把上一步输出里的 `task_id` 填到下面，模拟导航/抓取成功：

```bash
ros2 topic pub --once /retail_ai/task_status ylhb_interfaces/msg/TaskStatus \
  "{task_id: '替换成实际task_id', stage: 'place', status: 'succeeded', reason: ''}"
```

再测试结算：

```bash
ros2 topic pub --once /retail_ai/text_command std_msgs/msg/String "{data: '一共多少钱'}"
ros2 topic echo /retail_ai/cart --once
ros2 topic echo /retail_ai/say_text --once
```

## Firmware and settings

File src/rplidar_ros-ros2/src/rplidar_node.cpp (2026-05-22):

/*
 *  RPLIDAR ROS2 NODE
 *
 *  Copyright (c) 2009 - 2014 RoboPeak Team
 *  http://www.robopeak.com
 *  Copyright (c) 2014 - 2022 Shanghai Slamtec Co., Ltd.
 *  http://www.slamtec.com
 *
 */
/*
 * Redistribution and use in source and binary forms, with or without
 * modification, are permitted provided that the following conditions are met:
 *
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
 * THIS SOFTWARE IS PROVIDED BY THE COPYRIGHT HOLDERS AND CONTRIBUTORS "AS IS"
 * AND ANY EXPRESS OR IMPLIED WARRANTIES, INCLUDING, BUT NOT LIMITED TO,
 * THE IMPLIED WARRANTIES OF MERCHANTABILITY AND FITNESS FOR A PARTICULAR
 * PURPOSE ARE DISCLAIMED. IN NO EVENT SHALL THE COPYRIGHT HOLDER OR
 * CONTRIBUTORS BE LIABLE FOR ANY DIRECT, INDIRECT, INCIDENTAL, SPECIAL,
 * EXEMPLARY, OR CONSEQUENTIAL DAMAGES (INCLUDING, BUT NOT LIMITED TO,
 * PROCUREMENT OF SUBSTITUTE GOODS OR SERVICES; LOSS OF USE, DATA, OR PROFITS;
 * OR BUSINESS INTERRUPTION) HOWEVER CAUSED AND ON ANY THEORY OF LIABILITY,
 * WHETHER IN CONTRACT, STRICT LIABILITY, OR TORT (INCLUDING NEGLIGENCE OR
 * OTHERWISE) ARISING IN ANY WAY OUT OF THE USE OF THIS SOFTWARE,
 * EVEN IF ADVISED OF THE POSSIBILITY OF SUCH DAMAGE.
 *
 */

#include <rclcpp/rclcpp.hpp>
#include <sensor_msgs/msg/laser_scan.hpp>
#include <std_srvs/srv/empty.hpp>
#include "sl_lidar.h"
#include "math.h"

#include <signal.h>

#ifndef _countof
#define _countof(_Array) (int)(sizeof(_Array) / sizeof(_Array[0]))
#endif

#define DEG2RAD(x) ((x)*M_PI/180.)

#define ROS2VERSION "1.0.1"

enum {
    LIDAR_A_SERIES_MINUM_MAJOR_ID   = 0,
    LIDAR_S_SERIES_MINUM_MAJOR_ID   = 5,
    LIDAR_T_SERIES_MINUM_MAJOR_ID   = 8,
};

using namespace sl;

bool need_exit = false;

class RPlidarNode : public rclcpp::Node
{
  public:
    RPlidarNode(const rclcpp::NodeOptions& options = rclcpp::NodeOptions())
    : Node("rplidar_node", options)
    {

      
    }

  private:    
    void init_param()
    {
        this->declare_parameter<std::string>("channel_type","serial");
        this->declare_parameter<std::string>("tcp_ip", "192.168.0.7");
        this->declare_parameter<int>("tcp_port", 20108);
        this->declare_parameter<std::string>("udp_ip","192.168.11.2");
        this->declare_parameter<int>("udp_port",8089);
        this->declare_parameter<std::string>("serial_port", "/dev/ttyUSB0");
        this->declare_parameter<int>("serial_baudrate",1000000);
        this->declare_parameter<std::string>("frame_id","laser_frame");
        this->declare_parameter<bool>("inverted", false);
        this->declare_parameter<bool>("angle_compensate", false);
        this->declare_parameter<bool>("flip_x_axis", false);
        this->declare_parameter<bool>("auto_standby", false);
        this->declare_parameter<std::string>("topic_name",std::string("scan"));
        this->declare_parameter<std::string>("scan_mode",std::string());
        this->declare_parameter<float>("scan_frequency",10);
        
        this->get_parameter_or<std::string>("channel_type", channel_type, "serial");
        this->get_parameter_or<std::string>("tcp_ip", tcp_ip, "192.168.0.7"); 
        this->get_parameter_or<int>("tcp_port", tcp_port, 20108);
        this->get_parameter_or<std::string>("udp_ip", udp_ip, "192.168.11.2"); 
        this->get_parameter_or<int>("udp_port", udp_port, 8089);
        this->get_parameter_or<std::string>("serial_port", serial_port, "/dev/ttyUSB0"); 
        this->get_parameter_or<int>("serial_baudrate", serial_baudrate, 1000000/*256000*/);//ros run for A1 A2, change to 256000 if A3
        this->get_parameter_or<std::string>("frame_id", frame_id, "laser_frame");
        this->get_parameter_or<bool>("inverted", inverted, false);
        this->get_parameter_or<bool>("angle_compensate", angle_compensate, false);
        this->get_parameter_or<bool>("flip_x_axis", flip_x_axis, false);
        this->get_parameter_or<bool>("auto_standby", auto_standby, false);
        this->get_parameter_or<std::string>("topic_name", topic_name, "scan");
        this->get_parameter_or<std::string>("scan_mode", scan_mode, std::string());
        if(channel_type == "udp")
            this->get_parameter_or<float>("scan_frequency", scan_frequency, 20.0);
        else
            this->get_parameter_or<float>("scan_frequency", scan_frequency, 10.0);

        if (channel_type == "serial") {
            RCLCPP_INFO(this->get_logger(),
                        "RPLidar serial config: port=%s baudrate=%d frame_id=%s",
                        serial_port.c_str(), serial_baudrate, frame_id.c_str());
        }
    }

    bool getRPLIDARDeviceInfo(ILidarDriver * drv)
    {
        sl_result     op_result;
        sl_lidar_response_device_info_t devinfo;

        op_result = drv->getDeviceInfo(devinfo);
        if (SL_IS_FAIL(op_result)) {
            if (op_result == SL_RESULT_OPERATION_TIMEOUT) {
                RCLCPP_ERROR(this->get_logger(),"Error, operation time out. SL_RESULT_OPERATION_TIMEOUT! ");
            } else {
                RCLCPP_ERROR(this->get_logger(),"Error, unexpected error, code: %x",op_result);
            }
            return false;
        }

        // print out the device serial number, firmware and hardware version number..
        char sn_str[37] = {'\0'}; 
        for (int pos = 0; pos < 16 ;++pos) {
            sprintf(sn_str + (pos * 2),"%02X", devinfo.serialnum[pos]);
        }
        RCLCPP_INFO(this->get_logger(),"RPLidar S/N: %s",sn_str);
        RCLCPP_INFO(this->get_logger(),"Firmware Ver: %d.%02d",devinfo.firmware_version>>8, devinfo.firmware_version & 0xFF);
        RCLCPP_INFO(this->get_logger(),"Hardware Rev: %d",(int)devinfo.hardware_version);
        return true;
    }

    bool checkRPLIDARHealth(ILidarDriver * drv)
    {
        sl_result     op_result;
        sl_lidar_response_device_health_t healthinfo;
        op_result = drv->getHealth(healthinfo);
        if (SL_IS_OK(op_result)) { 
            RCLCPP_INFO(this->get_logger(),"RPLidar health status : %d", healthinfo.status);
            switch (healthinfo.status) {
                case SL_LIDAR_STATUS_OK:
                    RCLCPP_INFO(this->get_logger(),"RPLidar health status : OK.");
                    return true;
                case SL_LIDAR_STATUS_WARNING:
                    RCLCPP_INFO(this->get_logger(),"RPLidar health status : Warning.");
                    return true;
                case SL_LIDAR_STATUS_ERROR:
                    RCLCPP_ERROR(this->get_logger(),"Error, RPLidar internal error detected. Please reboot the device to retry.");
                    return false;
                default:
                    RCLCPP_ERROR(this->get_logger(),"Error, Unknown internal error detected. Please reboot the device to retry.");
                    return false;
            }
        } else {
            RCLCPP_ERROR(this->get_logger(),"Error, cannot retrieve RPLidar health code: %x", op_result);
            return false;
        }
    }

    bool stop_motor(const std::shared_ptr<std_srvs::srv::Empty::Request> req,
                    std::shared_ptr<std_srvs::srv::Empty::Response> res)
    {
        (void)req;
        (void)res;

        if (auto_standby) {
            RCLCPP_INFO(
                this->get_logger(),
                "Ingnoring stop_motor request because rplidar_node is in 'auto standby' mode");
            return false;
        }

        RCLCPP_DEBUG(this->get_logger(), "Call to '%s'", __FUNCTION__);
        
        //RCLCPP_DEBUG(this->get_logger(),"Stop motor");
        this->stop();
        //drv->setMotorSpeed(0);
        return true;
    }

    bool start_motor(const std::shared_ptr<std_srvs::srv::Empty::Request> req,
                    std::shared_ptr<std_srvs::srv::Empty::Response> res)
    {
        (void)req;
        (void)res;

        if (auto_standby) {
            RCLCPP_INFO(
                this->get_logger(),
                "Ingnoring start_motor request because rplidar_node is in 'auto standby' mode");
            return false;
        }
        RCLCPP_DEBUG(this->get_logger(), "Call to '%s'", __FUNCTION__);
        return this->start();

#if 0
        if(!drv)
           return false;
        if(drv->isConnected())
        {
            RCLCPP_DEBUG(this->get_logger(),"Start motor");
            sl_result ans=drv->setMotorSpeed();
            if (SL_IS_FAIL(ans)) {
                RCLCPP_WARN(this->get_logger(), "Failed to start motor: %08x", ans);
                return false;
            }
        
            ans=drv->startScan(0,1);
            if (SL_IS_FAIL(ans)) {
                RCLCPP_WARN(this->get_logger(), "Failed to start scan: %08x", ans);
            }
        } else {
            RCLCPP_INFO(this->get_logger(),"lost connection");
            return false;
        }

        return true;
#endif

    }

    static float getAngle(const sl_lidar_response_measurement_node_hq_t& node)
    {
        return node.angle_z_q14 * 90.f / 16384.f;
    }

    void publish_scan(rclcpp::Publisher<sensor_msgs::msg::LaserScan>::SharedPtr& pub,
                  sl_lidar_response_measurement_node_hq_t *nodes,
                  size_t node_count, rclcpp::Time start,
                  double scan_time, bool inverted, bool flip_X_axis,
                  float angle_min, float angle_max,
                  float max_distance,
                  std::string frame_id)
    {
        static int scan_count = 0;
        auto scan_msg = std::make_shared<sensor_msgs::msg::LaserScan>();

        scan_msg->header.stamp = start;
        scan_msg->header.frame_id = frame_id;
        scan_count++;

        bool reversed = (angle_max > angle_min);
        if ( reversed ) {
            scan_msg->angle_min =  M_PI - angle_max;
            scan_msg->angle_max =  M_PI - angle_min;
        } else {
            scan_msg->angle_min =  M_PI - angle_min;
            scan_msg->angle_max =  M_PI - angle_max;
        }
        scan_msg->angle_increment = (scan_msg->angle_max - scan_msg->angle_min) / (double)(node_count-1);

        scan_msg->scan_time = scan_time;
        scan_msg->time_increment = scan_time / (double)(node_count-1);
        scan_msg->range_min = 0.15;
        scan_msg->range_max = max_distance;//8.0;

        scan_msg->intensities.resize(node_count);
        scan_msg->ranges.resize(node_count);
        bool reverse_data = (!inverted && reversed) || (inverted && !reversed);

        size_t scan_midpoint = node_count / 2;
        for (size_t i = 0; i < node_count; i++) {
            float read_value = (float)nodes[i].dist_mm_q2 / 4.0f / 1000;
            size_t apply_index = i;
            if (reverse_data) {
                apply_index = node_count - 1 - i;
            }
            if (flip_X_axis) {
                if (apply_index >= scan_midpoint)
                    apply_index = apply_index - scan_midpoint;
                else
                    apply_index = apply_index + scan_midpoint;
            }

            if (read_value == 0.0)
                scan_msg->ranges[apply_index] = std::numeric_limits<float>::infinity();
            else
                scan_msg->ranges[apply_index] = read_value;
            scan_msg->intensities[apply_index] = (float)(nodes[apply_index].quality >> 2);
        }

        pub->publish(*scan_msg);
    }

    bool set_scan_mode() {
        sl_result     op_result;
        LidarScanMode current_scan_mode;
        if (scan_mode.empty()) {
            op_result = drv->startScan(false /* not force scan */, true /* use typical scan mode */, 0, &current_scan_mode);
        }
        else {
            std::vector<LidarScanMode> allSupportedScanModes;
            op_result = drv->getAllSupportedScanModes(allSupportedScanModes);

            if (SL_IS_OK(op_result)) {
                sl_u16 selectedScanMode = sl_u16(-1);
                for (std::vector<LidarScanMode>::iterator iter = allSupportedScanModes.begin(); iter != allSupportedScanModes.end(); iter++) {
                    if (iter->scan_mode == scan_mode) {
                        selectedScanMode = iter->id;
                        break;
                    }
                }

                if (selectedScanMode == sl_u16(-1)) {
                    RCLCPP_ERROR(this->get_logger(), "scan mode `%s' is not supported by lidar, supported modes:", scan_mode.c_str());
                    for (std::vector<LidarScanMode>::iterator iter = allSupportedScanModes.begin(); iter != allSupportedScanModes.end(); iter++) {
                        RCLCPP_ERROR(this->get_logger(), "\t%s: max_distance: %.1f m, Point number: %.1fK", iter->scan_mode,
                            iter->max_distance, (1000 / iter->us_per_sample));
                    }
                    op_result = SL_RESULT_OPERATION_FAIL;
                }
                else {
                    op_result = drv->startScanExpress(false /* not force scan */, selectedScanMode, 0, &current_scan_mode);
                }
            }
        }

        if (SL_IS_OK(op_result))
        {
            //default frequent is 10 hz (by motor pwm value),  current_scan_mode.us_per_sample is the number of scan point per us
            int points_per_circle = (int)(1000 * 1000 / current_scan_mode.us_per_sample / scan_frequency);
            angle_compensate_multiple = points_per_circle / 360.0 + 1;
            if (angle_compensate_multiple < 1)
                angle_compensate_multiple = 1.0;
            max_distance = (float)current_scan_mode.max_distance;
            RCLCPP_INFO(this->get_logger(), "current scan mode: %s, sample rate: %d Khz, max_distance: %.1f m, scan frequency:%.1f Hz, ",
                current_scan_mode.scan_mode, (int)(1000 / current_scan_mode.us_per_sample + 0.5), max_distance, scan_frequency);
            return true;
        }
        else
        {
            RCLCPP_ERROR(this->get_logger(), "Can not start scan: %08x!", op_result);
            return false;
        }
    }
    bool start()
    {
        if (nullptr == drv) {
            return false;
        }

        RCLCPP_INFO(this->get_logger(), "Start");
        drv->setMotorSpeed();
        if (!set_scan_mode()) {
            this->stop();
            RCLCPP_ERROR(this->get_logger(), "Failed to set scan mode");
            return false;
        }
        is_scanning = true;
        return true;
    }

    void stop()
    {
        if (nullptr == drv) {
            return;
        }

        RCLCPP_INFO(this->get_logger(), "Stop");
        drv->stop();
        drv->setMotorSpeed(0);
        is_scanning = false;
    }

public:    
    int work_loop()
    {        
        init_param();
        int ver_major = SL_LIDAR_SDK_VERSION_MAJOR;
        int ver_minor = SL_LIDAR_SDK_VERSION_MINOR;
        int ver_patch = SL_LIDAR_SDK_VERSION_PATCH;
        RCLCPP_INFO(this->get_logger(),"RPLidar running on ROS2 package rplidar_ros. RPLIDAR SDK Version:%d.%d.%d",ver_major,ver_minor,ver_patch);
    
        sl_result     op_result;
        // create the driver instance
        drv = *createLidarDriver();
        if (nullptr == drv) {
            /* don't start spinning without a driver object */
            RCLCPP_ERROR(this->get_logger(), "Failed to construct driver");
            return -1;
        }
        IChannel* _channel;
        if(channel_type == "tcp"){
            _channel = *createTcpChannel(tcp_ip, tcp_port);
        }
        else if(channel_type == "udp"){
            _channel = *createUdpChannel(udp_ip, udp_port);
        }
        else{
            _channel = *createSerialPortChannel(serial_port, serial_baudrate);
        }
        if (SL_IS_FAIL((drv)->connect(_channel))) {
            if(channel_type == "tcp"){
                RCLCPP_ERROR(this->get_logger(),"Error, cannot connect to the ip addr  %s with the tcp port %s.",tcp_ip.c_str(),std::to_string(tcp_port).c_str());
            }
            else if(channel_type == "udp"){
                RCLCPP_ERROR(this->get_logger(),"Error, cannot connect to the ip addr  %s with the udp port %s.",udp_ip.c_str(),std::to_string(udp_port).c_str());
            }
            else{
                RCLCPP_ERROR(this->get_logger(),"Error, cannot bind to the specified serial port %s.",serial_port.c_str());            
            }
            delete drv; drv = nullptr;
            return -1;
        }
        
        // get rplidar device info
        if (!getRPLIDARDeviceInfo(drv)) {
            delete drv; drv = nullptr;
            return -1;
        }

        // check health...
        if (!checkRPLIDARHealth(drv)) {
            delete drv; drv = nullptr;
            return -1;
        }

        sl_lidar_response_device_info_t devinfo;
        op_result = drv->getDeviceInfo(devinfo);
        bool scan_frequency_tunning_after_scan = false;

        if( (devinfo.model>>4) > LIDAR_S_SERIES_MINUM_MAJOR_ID){
            scan_frequency_tunning_after_scan = true;
        }

        if(!scan_frequency_tunning_after_scan){ //for RPLIDAR A serials
            //start RPLIDAR A serials  rotate by pwm
            drv->setMotorSpeed(600);
        }

        /* start motor and scanning */
        if (!auto_standby && !this->start()) {
            delete drv; drv = nullptr;
            return -1;
        }

        scan_pub = this->create_publisher<sensor_msgs::msg::LaserScan>(topic_name, rclcpp::QoS(rclcpp::KeepLast(10)));

        stop_motor_service = this->create_service<std_srvs::srv::Empty>("stop_motor",  
                                std::bind(&RPlidarNode::stop_motor,this,std::placeholders::_1,std::placeholders::_2));
        start_motor_service = this->create_service<std_srvs::srv::Empty>("start_motor", 
                                std::bind(&RPlidarNode::start_motor,this,std::placeholders::_1,std::placeholders::_2));

        //drv->setMotorSpeed();

        rclcpp::Time start_scan_time;
        rclcpp::Time end_scan_time;
        double scan_duration;
        while (rclcpp::ok() && !need_exit) {
            sl_lidar_response_measurement_node_hq_t nodes[8192];
            size_t   count = _countof(nodes);

            if (auto_standby) {
                if (scan_pub->get_subscription_count() > 0 && !is_scanning) {
                    this->start();
                }
                else if (scan_pub->get_subscription_count() == 0) {
                    if (is_scanning) {
                        this->stop();
                    }
                }
            }

            start_scan_time = this->now();
            op_result = drv->grabScanDataHq(nodes, count);
            end_scan_time = this->now();
            scan_duration = (end_scan_time - start_scan_time).seconds();

            if (op_result == SL_RESULT_OK) {
                if(scan_frequency_tunning_after_scan) { //Set scan frequency(For Slamtec Tof lidar)
                    RCLCPP_INFO(this->get_logger(), "set lidar scan frequency to %.1f Hz(%.1f Rpm) ",scan_frequency,scan_frequency*60);
                    drv->setMotorSpeed(scan_frequency*60); //rpm 
                    scan_frequency_tunning_after_scan = false;
                    continue;
                }
                op_result = drv->ascendScanData(nodes, count);
                float angle_min = DEG2RAD(0.0f);
                float angle_max = DEG2RAD(359.0f);
                if (op_result == SL_RESULT_OK) {
                    if (angle_compensate) {
                        //const int angle_compensate_multiple = 1;
                        const int angle_compensate_nodes_count = 360*angle_compensate_multiple;
                        int angle_compensate_offset = 0;
                        auto angle_compensate_nodes = new sl_lidar_response_measurement_node_hq_t[angle_compensate_nodes_count];
                        memset(angle_compensate_nodes, 0, angle_compensate_nodes_count*sizeof(sl_lidar_response_measurement_node_hq_t));

                        size_t i = 0, j = 0;
                        for( ; i < count; i++ ) {
                            if (nodes[i].dist_mm_q2 != 0) {
                                float angle = getAngle(nodes[i]);
                                int angle_value = (int)(angle * angle_compensate_multiple);
                                if ((angle_value - angle_compensate_offset) < 0) angle_compensate_offset = angle_value;
                                for (j = 0; j < angle_compensate_multiple; j++) {
                                    int angle_compensate_nodes_index = angle_value-angle_compensate_offset + j;
                                    if(angle_compensate_nodes_index >= angle_compensate_nodes_count)
                                        angle_compensate_nodes_index = angle_compensate_nodes_count - 1;
                                    angle_compensate_nodes[angle_compensate_nodes_index] = nodes[i];
                                }
                            }
                        }
    
                        publish_scan(scan_pub, angle_compensate_nodes, angle_compensate_nodes_count,
                                start_scan_time, scan_duration, inverted, flip_x_axis,
                                angle_min, angle_max, max_distance,
                                frame_id);

                        if (angle_compensate_nodes) {
                            delete[] angle_compensate_nodes;
                            angle_compensate_nodes = nullptr;
                        }
                    } else {
                        int start_node = 0, end_node = 0;
                        int i = 0;
                        // find the first valid node and last valid node
                        while (nodes[i++].dist_mm_q2 == 0);
                        start_node = i-1;
                        i = count -1;
                        while (nodes[i--].dist_mm_q2 == 0);
                        end_node = i+1;
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
int main(int argc, char * argv[])
{
  rclcpp::init(argc, argv);  
  auto rplidar_node = std::make_shared<RPlidarNode>(rclcpp::NodeOptions());
  signal(SIGINT,ExitHandler);
  int ret = rplidar_node->work_loop();
  rclcpp::shutdown();
  return ret;
}

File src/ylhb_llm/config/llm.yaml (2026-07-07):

retail_task_node:
  ros__parameters:
    # 商品库配置文件。里面维护 16 类商品的标准 ID、中文名、别名、价格、推荐权重。
    # 比赛现场如果商品名称、别名或价格变化，优先改这个文件，不改代码。
    products_file: /home/nvidia/ros2_ws/src/ylhb_llm/config/products.yaml

    # 文字任务输入话题。命令行输入和 voice_input_node 的 ASR 结果都会发到这里。
    # 示例内容：来瓶可乐 / 拿一瓶矿泉水 / 一共多少钱
    text_command_topic: /retail_ai/text_command

    # 视觉定位结果话题。来自 ylhb_perception/object_localizer_node.py。
    # retail_task_node 会用这个话题确认货架上真实存在的商品，避免大模型凭空推荐。
    localized_objects_topic: /perception/localized_objects

    # AI 层发给导航/抓取层的结构化任务事件话题。
    # 导航/抓取层应订阅它，然后执行去货架、抓取、去结算区、放置等动作。
    task_event_topic: /retail_ai/task_event

    # 导航/抓取层回传执行状态的话题。
    # B-1 用 inspect_shelf 成功触发真实货架推荐；B-2 用 place 成功入账；C 用 checkout_inspect/return_start 完成清单和总价播报。
    task_status_topic: /retail_ai/task_status

    # 播报请求话题。retail_task_node 把所有需要说的话发到这里。
    # voice_output_node 负责排队、TTS 和播放。
    say_text_topic: /retail_ai/say_text

    # B-2 销售对话状态。UI 订阅后显示主推商品、备选商品和最近回复。
    sales_dialogue_status_topic: /retail_ai/sales_dialogue_status

    # 购物车状态话题。用于调试结算区识别出的商品、数量和本地计算出的总价。
    cart_topic: /retail_ai/cart

    # B-1 任务启动服务。使用 std_srvs/srv/Trigger，任务层自己扫描 task_image_dir。
    start_b1_service_name: /retail_ai/start_b1_task

    # 任务书图片目录。B-1 要求目录内只有一张 jpg/jpeg/png 图片。
    task_image_dir: /home/nvidia/ros2_ws/src/ylhb_llm/test_images

    # 显示屏发布的全局系统模式：sleep/ready/mapping/running/fault。
    system_mode_topic: /retail_ai/system_mode

    # 货架识别结果有效期，单位秒。
    # 超过这个时间没有新的 /perception/localized_objects，就认为货架结果过期，不做最终推荐。
    shelf_snapshot_ttl_sec: 15.0
    vlm_shelf_request_topic: /retail_ai/vlm_shelf_request
    vlm_checkout_request_topic: /retail_ai/vlm_checkout_request

    # DashScope OpenAI 兼容接口地址。中国内地北京地域使用下面这个地址。
    # 如果使用国际/新加坡地域，需要换成 https://dashscope-intl.aliyuncs.com/compatible-mode/v1
    dashscope_base_url: https://dashscope.aliyuncs.com/compatible-mode/v1

    # 视觉理解模型。必须使用支持 image_url 的 VL 模型。
    vl_model: qwen3.7-plus

    # 文本意图解析模型。用于复杂口语、多轮补充、商品名称归一化。
    chat_model: qwen3.7-plus

    # B-2 语音实时分类模型：只做意图/类别/约束分类，最终选品和执行仍由本地状态机决定。
    fast_classifier_model: qwen3.6-flash
    classifier_timeout_sec: 4.0
    enable_fast_sales_classifier: true
    classifier_confidence_threshold: 0.72
    enable_plus_fallback: true
    plus_fallback_confidence_threshold: 0.62
    sales_reply_min_chars: 45
    sales_reply_max_chars: 70
    voice_requires_confirmation: true
    general_chat_history_timeout_sec: 35.0

    # 普通文本请求超时，单位秒。用于文字意图解析等。
    # 太短容易误判超时；太长会影响比赛 60 秒响应限制。
    request_timeout_sec: 12.0

    # 图片理解请求超时，单位秒。VL 模型第一次视觉请求可能较慢，所以默认 45 秒。
    # 如果比赛现场网络稳定，可调到 20~30；如果仍超时，可临时调到 60。
    vision_timeout_sec: 45.0

    # 是否在 TaskEvent.raw_json 和 CartState.raw_json 中保留调试 JSON。
    # 调试阶段建议 true；正式比赛如果想减少消息长度可设 false。
    publish_raw_json: true

basic_motion_command_node:
  ros__parameters:
    # A-1 基本运动语音/文字入口，和 ASR 结果共用同一个文字话题。
    text_command_topic: /retail_ai/text_command

    # 显示屏发布的全局系统模式。sleep/fault 下只响应停止；mapping 下允许手动建图运动。
    system_mode_topic: /retail_ai/system_mode

    # 底盘速度控制话题，base_controller 订阅该话题。
    cmd_vel_topic: /cmd_vel

    # 运动拒绝原因通过语音播报，ZLAC 状态用于避免向离线底盘发送非零速度。
    say_text_topic: /retail_ai/say_text
    zlac_status_topic: /zlac8015d/status

    # 基本运动调试速度。比赛 A-1 只需展示前进/后退/左转/右转，不追求高速。
    linear_speed: 0.12
    angular_speed: 0.45

    # 每条运动指令持续时间，到时自动发布零速度停止。
    motion_duration_sec: 1.0
    publish_rate_hz: 20.0
    require_chassis_online: true
    chassis_status_max_age_sec: 2.5

retail_display_ui_node:
  ros__parameters:
    text_command_topic: /retail_ai/text_command
    system_mode_topic: /retail_ai/system_mode
    system_command_topic: /retail_ai/system_command
    system_status_topic: /retail_ai/system_status
    task_event_topic: /retail_ai/task_event
    task_status_topic: /retail_ai/task_status
    say_text_topic: /retail_ai/say_text
    sales_dialogue_status_topic: /retail_ai/sales_dialogue_status
    voice_session_status_topic: /retail_ai/voice_session_status
    voice_command_event_topic: /retail_ai/voice_command_event
    cart_topic: /retail_ai/cart
    voice_status_topic: /retail_ai/voice_status
    start_voice_session_service_name: /retail_ai/start_voice_session
    stop_voice_session_service_name: /retail_ai/stop_voice_session
    capture_voice_service_name: /retail_ai/capture_voice
    localized_objects_topic: /perception/localized_objects
    start_b1_service_name: /retail_ai/start_b1_task
    task_image_dir: /home/nvidia/ros2_ws/src/ylhb_llm/test_images
    cmd_vel_topic: /cmd_vel
    zlac_status_topic: /zlac8015d/status
    chassis_status_max_age_sec: 2.5
    enable_voice_session: false
    enable_capture_voice: false
    enable_tts: false
    initial_system_mode: ready
    fullscreen: true
    display: ":0"
    force_local_display: true
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

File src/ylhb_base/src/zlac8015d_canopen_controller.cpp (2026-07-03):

#include <rclcpp/rclcpp.hpp>
#include <geometry_msgs/msg/twist.hpp>
#include <nav_msgs/msg/odometry.hpp>
#include <std_msgs/msg/string.hpp>
#include <tf2/LinearMath/Quaternion.h>
#include <tf2_geometry_msgs/tf2_geometry_msgs.hpp>
#include <tf2_ros/transform_broadcaster.h>

#include <linux/can.h>
#include <linux/can/raw.h>
#include <net/if.h>
#include <sys/ioctl.h>
#include <sys/socket.h>
#include <unistd.h>

#include <algorithm>
#include <array>
#include <cerrno>
#include <chrono>
#include <cmath>
#include <cstdint>
#include <cstring>
#include <iomanip>
#include <limits>
#include <memory>
#include <optional>
#include <sstream>
#include <string>
#include <utility>

#include "ylhb_base/zlac_drive_mapping.hpp"
#include "ylhb_base/zlac_status.hpp"

using namespace std::chrono_literals;
using ylhb_base::ChannelFaults;
using ylhb_base::ChannelRpm;
using ylhb_base::DifferentialDriveKinematics;
using ylhb_base::LogicalWheelRpm;
using ylhb_base::ZlacChannelMapping;
using ylhb_base::zlac_should_warn_cmd_timeout;
using ylhb_base::zlac_status_state;

namespace
{
constexpr uint16_t kControlWord = 0x6040;
constexpr uint16_t kStatusWord = 0x6041;
constexpr uint16_t kModesOfOperation = 0x6060;
constexpr uint16_t kActualVelocity = 0x606C;
constexpr uint16_t kTargetVelocity = 0x60FF;
constexpr uint16_t kProfileAcceleration = 0x6083;
constexpr uint16_t kProfileDeceleration = 0x6084;
constexpr uint16_t kFaultCode = 0x603F;
constexpr uint16_t kVendorControlMode = 0x200F;

std::string frame_to_string(const can_frame & frame)
{
  std::ostringstream out;
  out << std::hex << std::uppercase << std::setfill('0') << std::setw(3) << frame.can_id << "#";
  for (int i = 0; i < frame.can_dlc; ++i) {
    out << std::setw(2) << static_cast<int>(frame.data[i]);
  }
  return out.str();
}

std::string fault_text(uint16_t code)
{
  switch (code) {
    case 0x0000: return "no fault";
    case 0x0001: return "over voltage";
    case 0x0002: return "under voltage";
    case 0x0100: return "EEPROM read/write fault";
    case 0x0004: return "over current";
    case 0x0008: return "over load";
    case 0x0020: return "encoder deviation";
    case 0x0040: return "speed deviation";
    case 0x0080: return "reference voltage fault";
    case 0x0200: return "hall fault";
    case 0x0400: return "motor over temperature";
    case 0x0800: return "encoder fault";
    case 0x2000: return "target speed fault";
    default: break;
  }
  std::ostringstream out;
  out << "vendor fault 0x" << std::hex << std::uppercase << std::setw(4) << std::setfill('0') << code;
  return out.str();
}
}  // namespace

class Zlac8015DCanopenClient
{
public:
  struct SdoResponse
  {
    uint16_t index = 0;
    uint8_t subindex = 0;
    uint8_t command = 0;
    uint32_t raw = 0;
    uint8_t size = 0;
  };

  enum class EventType
  {
    Heartbeat,
    SdoResponse
  };

  struct CanEvent
  {
    EventType type = EventType::SdoResponse;
    uint8_t heartbeat_state = 0;
    SdoResponse sdo {};
  };

  Zlac8015DCanopenClient(
    const std::string & interface_name, uint8_t node_id, int sdo_timeout_ms,
    double target_velocity_unit_per_rpm, double actual_velocity_unit_per_rpm,
    rclcpp::Logger logger)
  : interface_name_(interface_name),
    node_id_(node_id),
    sdo_timeout_ms_(sdo_timeout_ms),
    target_velocity_unit_per_rpm_(target_velocity_unit_per_rpm),
    actual_velocity_unit_per_rpm_(actual_velocity_unit_per_rpm),
    logger_(logger)
  {
  }

  ~Zlac8015DCanopenClient()
  {
    close_socket();
  }

  bool open_socket()
  {
    socket_fd_ = socket(PF_CAN, SOCK_RAW | SOCK_NONBLOCK, CAN_RAW);
    if (socket_fd_ < 0) {
      RCLCPP_ERROR(logger_, "Failed to create SocketCAN socket: %s", std::strerror(errno));
      return false;
    }

    ifreq ifr {};
    std::strncpy(ifr.ifr_name, interface_name_.c_str(), IFNAMSIZ - 1);
    if (ioctl(socket_fd_, SIOCGIFINDEX, &ifr) < 0) {
      RCLCPP_ERROR(logger_, "CAN interface %s is not available: %s",
        interface_name_.c_str(), std::strerror(errno));
      close_socket();
      return false;
    }

    sockaddr_can addr {};
    addr.can_family = AF_CAN;
    addr.can_ifindex = ifr.ifr_ifindex;
    if (bind(socket_fd_, reinterpret_cast<sockaddr *>(&addr), sizeof(addr)) < 0) {
      RCLCPP_ERROR(logger_, "Failed to bind %s: %s", interface_name_.c_str(), std::strerror(errno));
      close_socket();
      return false;
    }
    return true;
  }

  bool is_open() const { return socket_fd_ >= 0; }

  void close_socket()
  {
    if (socket_fd_ >= 0) {
      close(socket_fd_);
      socket_fd_ = -1;
    }
  }

  bool send_nmt_start()
  {
    can_frame frame {};
    frame.can_id = 0x000;
    frame.can_dlc = 2;
    frame.data[0] = 0x01;
    frame.data[1] = node_id_;
    return send_frame(frame);
  }

  bool write_u8(uint16_t index, uint8_t subindex, uint8_t value)
  {
    return send_sdo_write(index, subindex, 0x2F, value);
  }

  bool write_u16(uint16_t index, uint8_t subindex, uint16_t value)
  {
    return send_sdo_write(index, subindex, 0x2B, value);
  }

  bool write_i32(uint16_t index, uint8_t subindex, int32_t value)
  {
    return send_sdo_write(index, subindex, 0x23, static_cast<uint32_t>(value));
  }
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

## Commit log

2026-05-04 Initial commit: ROS2 smart retail robot
    [ylhb.urdf.xacro, zed_descr.urdf.xacro, zed_macro.urdf.xacro]
2026-05-10 Fix DashScope ASR and update voice
    [llm.yaml]
2026-05-10 Improve B2 voice dialogue stability
    [llm.yaml]
2026-05-10 Fix voice session timeout and TTS segmentation
    [llm.yaml]
2026-05-12 Improve voice diagnostics and sales correction
    [llm.yaml]
2026-05-12 chore: 优化 git 发布脚本重试和预览
2026-05-18 feat: add ZLAC8015D SocketCAN chassis backend
    [robot_geometry.yaml]
2026-05-18 fix: update zlac backend and readme cover
    [base_kinematics.yaml, zlac8015d.yaml, zlac8015d_canopen_controller.cpp]
2026-05-19 add retail cart 3D model folder
    [万向轮.SLDASM, 万向轮.SLDPRT, 万向轮底座.SLDPRT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]
2026-05-20 fix: switch ZLAC base to PCAN can1
    [zlac8015d.yaml]
2026-05-21 Update retail cart 3D model files under CAD
    [小车底盘 - 万向轮-1 万向轮-1.STL, 小车底盘 - 万向轮-1 万向轮底座-1.STL, 小车底盘 - 万向轮-1 万向轮支架-1.STL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]
2026-05-22 fix: stabilize lidar and imu serial bringup
    [rplidar_node.cpp]
2026-05-23 fix: tune Nav2 footprint and low-speed limits
    [ylhb.urdf.xacro]
2026-05-23 fix: tune Nav2 real robot navigation
    [base_kinematics.yaml]
2026-05-24 fix: stabilize Nav2 startup localization
    [ekf.yaml, llm.yaml]
2026-06-14 Add robotic arm models and update retail cart assembly
    [伸缩杆.SLDPRT, 伸缩杆固定底座.SLDPRT, 伸缩杆支架盖子.SLDPRT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]
2026-06-15 fix: stabilize voice and chassis command handling
    [llm.yaml]
2026-06-15 fix: calibrate ZLAC drive mapping and sensor frames
    [ylhb.urdf.xacro]
2026-07-03 fix: correct retail competition safe timing
    [llm.yaml]
2026-07-06 Update retail cart CAD model
    [5G模块.SLDPRT, 5G盖子.SLDPRT, 万向轮.SLDASM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]
2026-07-06 Add CAD model reference images

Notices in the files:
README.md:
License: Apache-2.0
